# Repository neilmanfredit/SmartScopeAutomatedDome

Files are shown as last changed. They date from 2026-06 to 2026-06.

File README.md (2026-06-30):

# SmartScopeAutomatedDome

> **3D-printed automated observatory domes for the ZWO Seestar S50**  
> Three versions — choose the one that fits your setup and ambition.






---

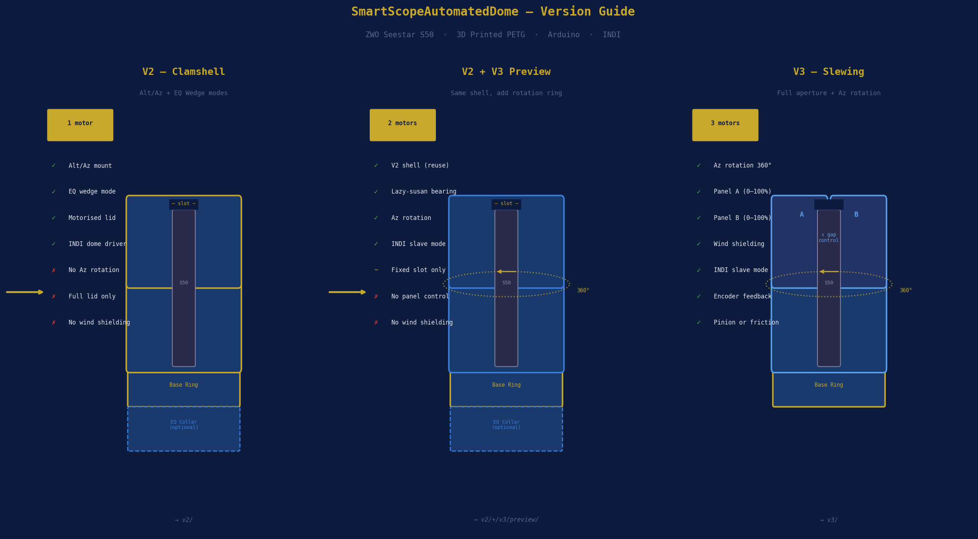
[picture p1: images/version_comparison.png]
Version Comparison


---

## Which version do I need?

Three versions exist, each adding capability on top of the last. You don't need to start at V2 — pick the one that matches what you actually want to do.

| | [V2 — Clamshell](#v2--clamshell) | [V3 — Slewing](#v3--slewing-dome) |
|---|---|---|
| **Best for** | Protecting scope overnight, simple open/close | Unattended imaging, wind shielding, precise aperture |
| **Modes** | Alt/Az + EQ wedge | Alt/Az + EQ wedge |
| **Motors** | 1 (opens lid) | 3 (Az rotation + Panel A + Panel B) |
| **Controller** | Arduino Nano | Arduino Mega 2560 |
| **Dome rotation** | Static | 360° motorised |
| **Aperture** | Full lid open or closed | Two independent panels, 0–100% each |
| **Wind shielding** | None | Yes — closed side always faces wind |
| **INDI slave mode** | No | Yes — dome tracks scope azimuth automatically |
| **Az encoder** | None | TCRT5000 IR, 36-slot, 0.0375°/step |
| **Drive options** | M8 lead screw | Ring gear + pinion OR friction wheel |
| **Est. build cost** | ~£89 | ~£140 |
| **Est. print time** | ~25 h | ~38 h |
| **Complexity** | Moderate | High |
| **README** | **[→ v2/README.md](v2/README.md)** | **[→ v3/README_V3_ADDENDUM.md](v3/README_V3_ADDENDUM.md)** |

---

## V2 — Clamshell

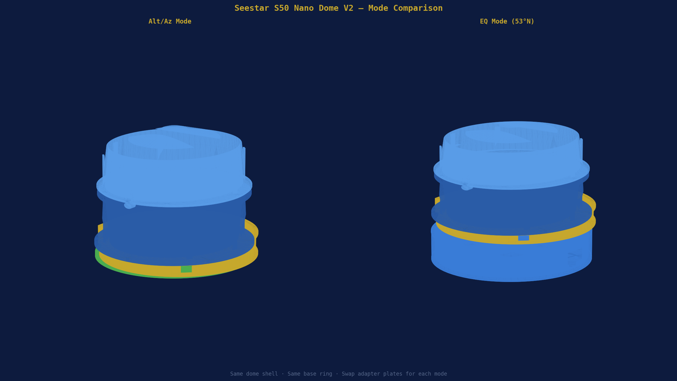
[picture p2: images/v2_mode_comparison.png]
V2 Mode Comparison


**The right choice if:** you want a dome that opens and closes to protect the scope, works in both Alt/Az and EQ modes, and you want something straightforward to build and commission.

V2 is a motorised clamshell — one NEMA 17 stepper drives an M8 lead screw that lifts the upper half of the dome. The dome sits still; only the lid moves. An Arduino Nano presents a serial command interface and the INDI driver handles open, close, park, and abort from within KStars/Ekos.

The key design decision in V2 is the **swappable adapter plate** — one base ring works for both modes:

- **Alt/Az** — adapter plate threads straight onto the S50 tripod
- **EQ** — a 110 mm extension collar raises the dome over your existing wedge

The dome interior (252 × 230 mm) gives the S50 complete freedom of movement. No scope-locating ribs — the scope floats inside the cavity in any position.

**[→ Full V2 README and build guide](v2/README.md)**

---

## V3 — Slewing Dome

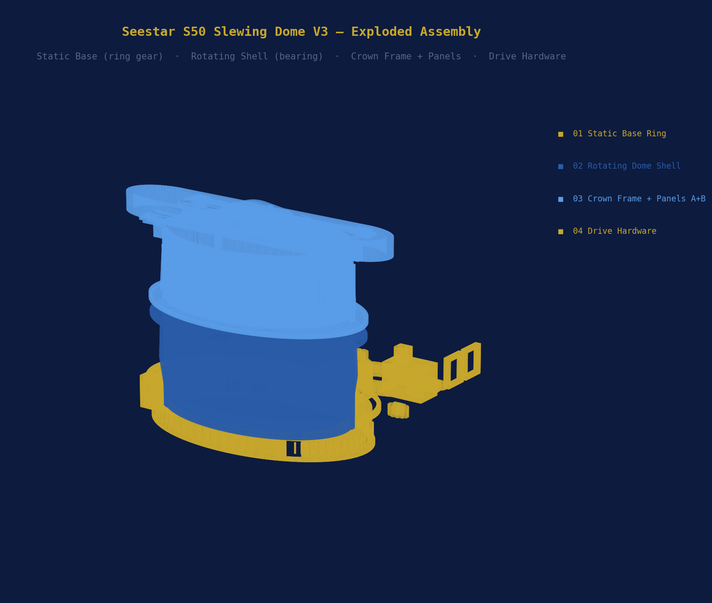
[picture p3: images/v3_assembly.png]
V3 Assembly


**The right choice if:** you want the dome to track the scope automatically, shield the scope from wind on the closed side, and control exactly how wide the aperture is.

V3 keeps the same dome shell dimensions as V2 but adds a **300 mm lazy-susan bearing** so the whole dome rotates in azimuth under Motor 1. The crown slot is replaced by two independently driven panels — Motor 2 moves Panel A, Motor 3 moves Panel B — each on its own M6 lead screw and LM8UU linear guide.

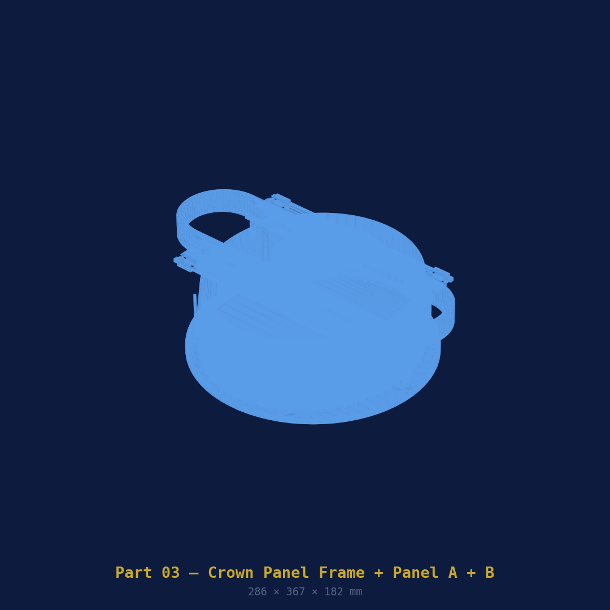
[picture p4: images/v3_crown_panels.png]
V3 Crown Panels


In INDI slave mode the driver reads the mount's RA/Dec, converts to azimuth, and slews the dome every 5 seconds (configurable) to keep the opening aligned with the telescope. A 2° dead-band prevents hunting on minor mount movements. The closed side of the dome permanently blocks wind and dew from the opposite direction.

Two Az drive mechanisms are included in the files — choose at assembly time:

- **Ring gear + pinion** — 72:12 = 6:1 reduction, 0.0375°/step, fully printed
- **Friction wheel** — rubber wheel presses on dome outer rim, simpler to set up

**V3 uses the same base ring bottom flange as V2**, so the Alt/Az and EQ adapter plates from V2 carry across directly. No reprinting the adapters.

**[→ Full V3 README and build guide](v3/README_V3_ADDENDUM.md)**

---

## Shared architecture

Both versions are built on the same mechanical and software foundations.

### Dome shell

All versions use the same outer dome geometry — 261 × 239 mm outer, 252 × 230 mm interior. The S50 (142.5 × 130 × 257 mm body) has 55 mm clearance each side, 50 mm front/rear, and 40 mm above. The clearances are designed around the worst-case EQ mode position at 53°N latitude (Stockport) — the scope tilted 53° on the polar axis, rotating through all RA positions. At no point does the scope contact the dome interior.

### INDI integration

Both drivers appear under the **Domes** group in KStars/Ekos. Both implement the INDI Dome interface — open, close, park, abort. V3 adds `DOME_CAN_ROTATE`, `DOME_CAN_SYNC`, and INDI slave mode. Standard Ekos observatory automation works with both.

### Firmware protocol

Both use plain-text serial at 9600 baud. Commands are human-readable (`OPEN`, `CLOSE`, `GOTO 180.0`, `STATUS`). You can test the dome from any terminal — no special tools needed.

### Materials and print settings

All parts: **PETG on Bambu Lab H2S**, 0.20 mm layer height, 30% Gyroid infill, 4 walls, tree supports. Settings are embedded in every `.3mf` file. The large dome shells and base ring require the H2S **320 × 320 mm extended build volume** — rotate the base ring 45° in Bambu Studio to fit.

---

## Repository structure

```
SmartScopeAutomatedDome/
│
├── README.md                    ← You are here
│
├── v2/                          ← Clamshell dome (Alt/Az + EQ)
│   ├── README.md                ← Full V2 build guide
│   ├── openscad/                ← 7 .scad source files
│   ├── 3mf/                     ← 6 Bambu Studio .3mf files
│   ├── firmware/                ← Arduino Nano firmware
│   ├── indi/                    ← INDI dome driver (clamshell)
│   └── images/                  ← 11 renders and diagrams
│
├── v3/                          ← Slewing dome (Az rotation + panels)
│   ├── README_V3_ADDENDUM.md    ← Full V3 build guide
│   ├── openscad/                ← 5 .scad source files
│   ├── 3mf/                     ← 4 Bambu Studio .3mf files
│   ├── firmware/                ← Arduino Mega 2560 firmware
│   ├── indi/                    ← INDI slewing dome driver
│   └── images/                  ← 6 renders and diagrams
│
└── images/                      ← Main README images
    ├── version_comparison.png
    ├── v2_mode_comparison.png
    ├── v2_altaz_assembly.png
    ├── v3_assembly.png
    └── v3_crown_panels.png
```

---

## Quick start

**V2:**
```bash
# Print: v2/3mf/01_base_ring.3mf through 05_hardware_parts.3mf
# Upload firmware
arduino-cli compile --fqbn arduino:avr:nano v2/firmware/dome_controller/dome_controller.ino
arduino-cli upload -p /dev/ttyUSB0 --fqbn arduino:avr:nano v2/firmware/dome_controller/dome_controller.ino
# Build and install INDI driver
cd v2/indi && mkdir build && cd build && cmake -DCMAKE_INSTALL_PREFIX=/usr .. && make -j4 && sudo make install
indiserver -v indi_seestar_nano_dome
```

**V3:**
```bash
# Print: v3/3mf/01_base_ring.3mf through 04_drive_hardware.3mf
# Upload firmware (Arduino Mega)
arduino-cli compile --fqbn arduino:avr:mega v3/firmware/dome_controller_v3/dome_controller_v3.ino
arduino-cli upload -p /dev/ttyUSB0 --fqbn arduino:avr:mega v3/firmware/dome_controller_v3/dome_controller_v3.ino
# Build and install INDI driver
cd v3/indi && mkdir build && cd build && cmake -DCMAKE_INSTALL_PREFIX=/usr .. && make -j4 && sudo make install
indiserver -v indi_seestar_slewing_dome
```

---

## Parts sourcing

All hardware links (AliExpress search URLs) are in each version's README under the Bill of Materials section.

Common to both versions: NEMA 17 stepper, A4988 driver, M8 stainless rod, F688ZZ bearing, Omron SS-5GL limit switches, M4/M5 fasteners, PETG filament.

V3 additions: 300 mm lazy-susan bearing, 8 mm guide rods, LM8UU linear bearings, M6 threaded rod, TCRT5000 IR sensor, Arduino Mega 2560, 30 mm rubber wheel.

---

## Scope compatibility

The dome interior dimensions are sized for the **ZWO Seestar S50** (142.5 × 130 × 257 mm). To adapt for a different scope, edit `openscad/params.scad` in either version — update `s50_w`, `s50_d`, `s50_h` and re-export. All clearances and bearing seats recalculate automatically.

Tested clearances work for the **S50 in equatorial mode at 53°N**. For other latitudes, update `LATITUDE` in `params.scad`.

---

## Contributing

Issues and pull requests welcome. Before starting significant structural changes please open an issue to align on approach.

If you build either version, photos of the completed dome are very welcome — open a Discussion.

---

## Licence

Copyright © Neil Manfred. Licensed under the Creative Commons Attribution-NonCommercial-NoDerivatives 4.0 International License. Commercial use and derivative works are not permitted. — see [LICENSE](LICENSE) — CC BY-NC-SA 4.0, non-commercial use only.

---

*Built by [@neilmanfredit](https://github.com/neilmanfredit)*

---

## Gallery

### M42 — Orion Nebula

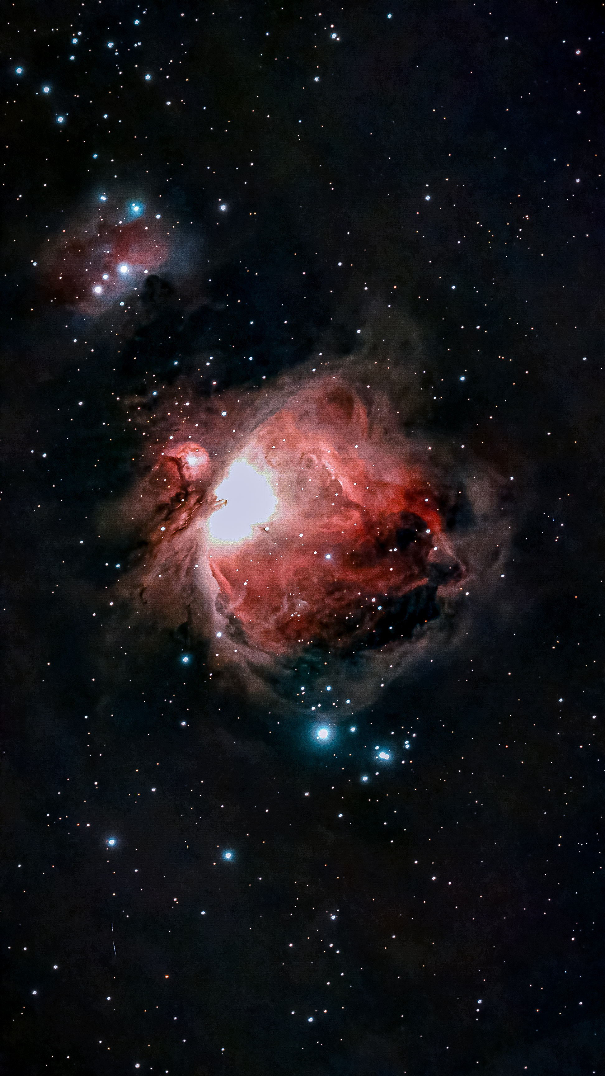
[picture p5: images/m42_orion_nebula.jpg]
Seestar S50 picture of M42


*Captured with the ZWO Seestar S50, 31 December 2025 — Bodmin Moor, Cornwall.*

The Orion Nebula (M42) captured from Bodmin Moor on New Year's Eve 2025. Bodmin Moor is one of the darkest sites in southern England, and the skies here show it — the image reveals the Trapezium cluster blazing at the core, four young massive stars responsible for ionising the surrounding gas and producing the characteristic red hydrogen-alpha glow. The Running Man Nebula (NGC 1977) is visible in the upper left, its blue reflection nebulosity contrasting with the warmer tones of M42. Dark dust lanes cut through the nebula, forming the distinctive fish-mouth shape around the bright central region. The Orion Nebula sits approximately 1,344 light years from Earth and is one of the most studied star-forming regions in the Milky Way. A stellar result from a 50mm aperture scope under genuinely dark skies.

---

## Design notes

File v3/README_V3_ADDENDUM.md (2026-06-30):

# V3 Addendum — Slewing Dome with Independent Aperture Panels

> This addendum extends the [main README](../README.md).  
> V3 adds full azimuth rotation and two independently controlled crown panels.

---

V3 Assembly

---

## What V3 Adds

| Feature | V2 Clamshell | V3 Slewing |
|---|---|---|
| Dome rotation | Static | Full 360° Az rotation |
| Aperture control | One motor opens full lid | Two independent panels (0–100%) |
| Wind shielding | None | Closed side always faces wind |
| Motors | 1 | 3 (Az + Panel A + Panel B) |
| Controller | Arduino Nano | Arduino Mega 2560 |
| Az feedback | None | TCRT5000 IR encoder, 36-slot disk |
| INDI slave mode | No | Yes — dome tracks scope Az automatically |
| Drive options | Lead screw | Ring gear + pinion OR friction wheel |

---

## How It Works

The dome shell sits on a **300 mm lazy-susan bearing** and rotates freely over the static base ring. A NEMA 17 motor (Motor 1) drives the dome in azimuth — either via a **printed ring gear + pinion** (72:12 = 6:1 ratio, 0.0375°/step resolution) or a **rubber friction wheel** pressing on the smooth outer rim. Both drive options are included in the files; choose at assembly time.

At the crown, two sliding panels (Panel A left, Panel B right) move independently on 8 mm guide rods driven by M6 × 1.0 mm lead screws (Motor 2 and Motor 3). Each panel can be positioned from fully closed to fully open (85 mm travel). This lets you dial in exactly how wide the aperture is and which side is shielded.

In INDI slave mode the driver reads the mount's RA/Dec every 5 seconds (configurable), converts to azimuth, and slews the dome to keep the open gap aligned with the scope. The 2° dead-band (configurable) prevents hunting on minor mount movements.

---

## System Architecture

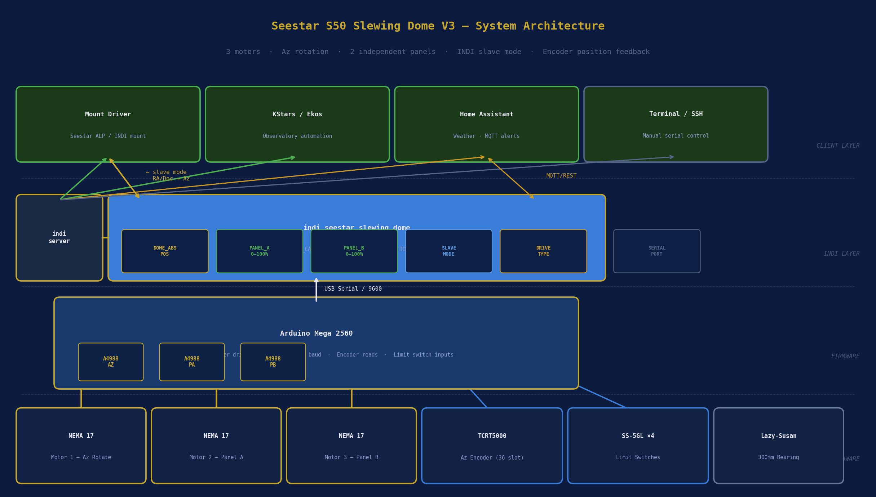
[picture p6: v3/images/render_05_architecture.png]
Architecture


| Layer | Component | Role |
|---|---|---|
| **Hardware** | 3× NEMA 17 + 3× A4988 + TCRT5000 + 4× SS-5GL | Motion + sensing |
| **Firmware** | Arduino Mega 2560 (`dome_controller_v3.ino`) | Serial command interface |
| **INDI** | `indi_seestar_slewing_dome` | Full slewing dome driver |
| **Client** | KStars/Ekos + Seestar ALP + HA | Control, slave mode, weather |

---

## Printed Parts

### Part 01 — Static Base Ring V3

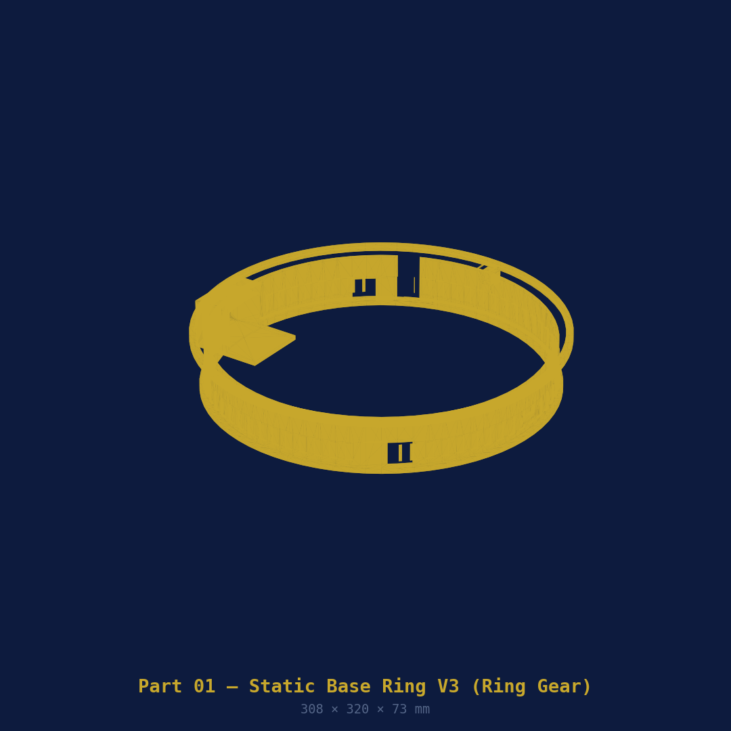
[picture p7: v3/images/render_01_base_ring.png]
Base Ring


Sits on the tripod or EQ extension (from V2 — fully compatible). Does not rotate.  
Contains the ring gear (72 teeth, module 2) on its outer rim for pinion drive, a smooth outer rail for friction drive, the Az motor pocket, the Az encoder IR sensor bracket, and an enlarged electronics bay (Arduino Mega 2560 + 3× A4988).

| Property | Value |
|---|---|
| File | `openscad/01_base_ring.scad` |
| 3MF | `3mf/01_base_ring.3mf` |
| Outer diameter | ~314 mm + gear teeth |
| Est. print time | ~7 h |
| Filament | ~260 g PETG |
| Orientation | Flat, open top face up |
| Supports | None |
| Bed | 320 × 320 mm — rotate 45° |

---

### Part 02 — Rotating Dome Shell V3

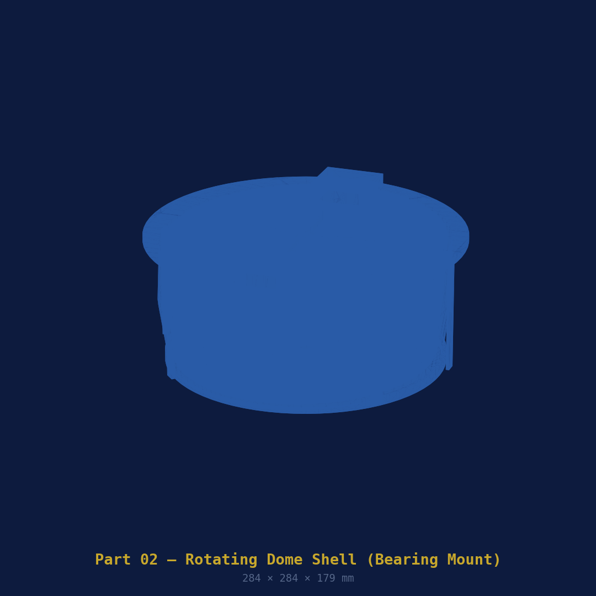
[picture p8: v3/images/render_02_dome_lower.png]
Dome Shell


This part **rotates** on the lazy-susan bearing. The bearing inner race (240 mm) bolts to the shell underside with 8× M4 bolts. The two panel motors (NEMA 17 #2 and #3) mount on the crown rim and rotate with the shell. The Az encoder disk attaches to the centre hub underneath.

| Property | Value |
|---|---|
| File | `openscad/02_dome_lower.scad` |
| 3MF | `3mf/02_dome_lower.3mf` |
| Interior | 252 × 230 mm — scope floats freely |
| Bearing seat | 240 mm ID (lazy-susan inner race) |
| Est. print time | ~11 h |
| Filament | ~330 g PETG |
| Orientation | Flat bottom on plate, interior up |
| Supports | Tree auto |
| Bed | 320 × 320 mm |

---

### Part 03 — Crown Panel Frame + Panel A + Panel B

Crown Panels

Three items in one file — export the frame and each panel separately for printing.

The **Crown Frame** bolts to the dome shell top flange and houses the full-length slot, the 8 mm guide rods, and the M6 lead screw bores. **Panel A** (left, Motor 2) and **Panel B** (right, Motor 3) each ride on two LM8UU linear bearings along the guide rods. Each panel has a captured M6 nut with anti-rotation tab. The panels overlap by 10 mm at centre when both are closed.

| Item | Print time | Filament |
|---|---|---|
| Crown Frame | ~8 h | ~250 g |
| Panel A | ~2 h | ~70 g |
| Panel B | ~2 h | ~70 g |

| Property | Value |
|---|---|
| File | `openscad/03_crown_panels.scad` |
| 3MF | `3mf/03_crown_panels.3mf` |
| Slot width (max open) | 80 mm |
| Panel travel | 85 mm each |
| Guide rods | 8 mm OD × 290 mm (order separately) |
| Linear bearings | LM8UU (order separately) |
| Orientation | Frame: split face down. Panels: flat. |
| Supports | Frame: tree auto. Panels: none. |

---

### Part 04 — Drive Hardware Parts V3

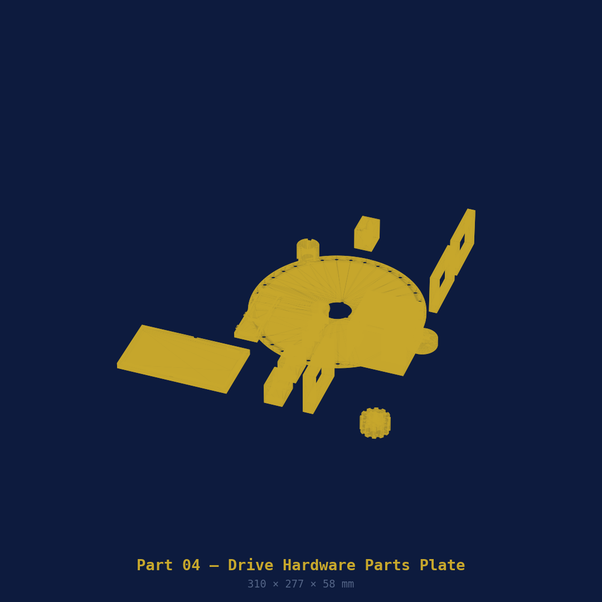
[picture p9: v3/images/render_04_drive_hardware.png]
Drive Hardware


All small parts on one plate. Export by module name for individual printing.

| Sub-part | Qty | Purpose |
|---|-----|---|
| Az pinion gear (04a) | 1 | Module 2, 12T — meshes with base ring (pinion drive) |
| Friction wheel mount (04b) | 1 | Holds NEMA 17 + rubber wheel on dome rim |
| Az motor bracket (04c) | 1 | Mounts Az NEMA 17 in base ring rear |
| Panel motor bracket (04d) | 2 | Mounts Panel A+B motors at crown |
| M6 bearing block (04e) | 2 | Lead screw lower end, F626ZZ bearing |
| M6 pivot arm (04f) | 2 | Connects M6 rod to panel |
| Az encoder disk (04g) | 1 | 36-slot, mounts on dome shell underside hub |
| IR sensor bracket (04h) | 1 | Mounts TCRT5000 on base ring, faces disk |
| Arduino Mega tray (04i) | 1 | Snap-fit, electronics bay |
| Triple A4988 tray (04j) | 1 | 3× drivers side by side, labelled AZ/PA/PB |
| Slip-ring spacer (04k) | 1 | Cable management through centre bore |

---

## Additional Hardware (V3 only)

> 💡 Prices are approximate AliExpress pricing at time of writing and will vary by seller. V3-specific hardware only — common items shared with V2 (M8 rod, F688ZZ bearing, M4/M5 fasteners, etc.) are in the [main V2 BOM](../v2/README.md#bill-of-materials) and not repeated here.

| Item | Qty | Approx. Cost | AliExpress |
|---|-----|---|---|
| 300 mm lazy-susan bearing | 1 | £9 | [🔗 Search](https://www.aliexpress.com/w/wholesale-300mm-lazy-susan-bearing-turntable.html) |
| 8 mm OD smooth rod, 300 mm (guide rods) | 2 | £6 | [🔗 Search](https://www.aliexpress.com/w/wholesale-8mm-smooth-rod-300mm-linear.html) |
| LM8UU linear bearing | 4 | £4 | [🔗 Search](https://www.aliexpress.com/w/wholesale-lm8uu-linear-bearing.html) |
| M6 × 1.0 threaded rod, 150 mm (×2) | 2 | £4 | [🔗 Search](https://www.aliexpress.com/w/wholesale-m6-threaded-rod-150mm-stainless.html) |
| F626ZZ flanged bearing (6×19×6) | 2 | £3 | [🔗 Search](https://www.aliexpress.com/w/wholesale-f626zz-flanged-bearing.html) |
| M6 flexible shaft coupler 5 mm→6 mm | 2 | £4 | [🔗 Search](https://www.aliexpress.com/w/wholesale-flexible-shaft-coupler-5mm-6mm.html) |
| NEMA 17 stepper motor (×3 total) | 3 | £30 | [🔗 Search](https://www.aliexpress.com/w/wholesale-nema-17-stepper-motor-40mm.html) |
| A4988 stepper driver with heatsink (×3) | 3 | £9 | [🔗 Search](https://www.aliexpress.com/w/wholesale-a4988-stepper-driver-heatsink.html) |
| Arduino Mega 2560 | 1 | £12 | [🔗 Search](https://www.aliexpress.com/w/wholesale-arduino-mega-2560-ch340.html) |
| TCRT5000 IR reflective sensor | 1 | £2 | [🔗 Search](https://www.aliexpress.com/w/wholesale-tcrt5000-ir-reflective-sensor.html) |
| Omron SS-5GL micro-switch (×4 total) | 4 | £6 | [🔗 Search](https://www.aliexpress.com/w/wholesale-omron-ss-5gl-micro-switch.html) |
| 30 mm rubber wheel (friction drive) | 1 | £3 | [🔗 Search](https://www.aliexpress.com/w/wholesale-30mm-rubber-wheel-shaft.html) |
| 6-wire slip ring, 12 mm OD | 1 | £6 | [🔗 Search](https://www.aliexpress.com/w/wholesale-6-wire-slip-ring-12mm.html) |
| **V3-specific subtotal** | | **£98** | |

> **Slip ring note:** The 6-wire slip ring routes the panel motor wires (6 wires: coil A+B for Motor 2, coil A+B for Motor 3, plus 2 limit switch wires) through the dome centre bore as it rotates. You can omit it if you have sufficient cable slack for 360° rotation without a slip ring — 500 mm of extra cable on each wire is usually enough for a dome that only ever sweeps ±180°. Omitting it saves £6.

### Total Build Cost (V3 complete)

V3 reuses the M8 lead screw, F688ZZ bearing, fasteners, foam seal, and tripod/EQ adapter hardware from V2 — those costs carry over alongside the V3-specific items above.

| | Without filament | With filament |
|---|---|---|
| V2 shared hardware (excl. filament) | £53 | £53 |
| V3-specific hardware (above) | £98 | £98 |
| PETG filament (~5 spools total, V2 dome shells + V3 parts) | — | £70 |
| **Total** | **£151** | **£221** |

> Filament estimate covers all V3 plates (base ring ~260g, dome shell ~330g, crown frame + panels ~390g, drive hardware ~110g — roughly 1.1kg / 1.5 spools) plus the shared V2 dome shells if not already printed (~3 spools). If you've already built V2 and are upgrading to V3, you only need the extra ~1.5 spools for the new V3-specific parts, bringing the incremental cost to roughly **£98–£130** depending on spool pricing.

---

## Firmware

Source: [`firmware/dome_controller_v3/dome_controller_v3.ino`](firmware/dome_controller_v3/dome_controller_v3.ino)

**Target:** Arduino Mega 2560 (not Nano — needs 11 digital outputs for 3× motor drivers)

### Serial Command Reference

| Command | Response | Description |
|---|---|---|
| `GOTO ddd.d` | `SLEWING:ddd.d` → `AZ_DONE:ddd.d` | Slew to azimuth |
| `SYNC ddd.d` | `SYNCED:ddd.d` | Set current position |
| `STATUS` | `AZ:ddd.d PA:nn PB:nn MOVING:n` | Full status |
| `STOP` / `ABORT` | `STOPPED` | Halt all motors |
| `PA OPEN` | `PA_DONE:136000` | Panel A fully open |
| `PA CLOSE` | `PA_DONE:0` | Panel A fully closed |
| `PA POS nn` | `PA_DONE:nnnnnn` | Panel A to nn% |
| `PB OPEN` | `PB_DONE:136000` | Panel B fully open |
| `PB CLOSE` | `PB_DONE:0` | Panel B fully closed |
| `PB POS nn` | `PB_DONE:nnnnnn` | Panel B to nn% |
| `PANELS OPEN` | `PANELS_OPEN` | Both panels fully open |
| `PANELS CLOSE` | `PANELS_CLOSED` | Both panels closed |
| `PARK` | `PARKED` | Close panels, slew to Az 0° |
| `HOME` | `HOMED` / `HOME_FAILED` | Home encoder on slot transition |

### Upload

```bash
arduino-cli core install arduino:avr
arduino-cli compile --fqbn arduino:avr:mega \
  firmware/dome_controller_v3/dome_controller_v3.ino
arduino-cli upload -p /dev/ttyUSB0 --fqbn arduino:avr:mega \
  firmware/dome_controller_v3/dome_controller_v3.ino
```

---

## INDI Driver

Source: [`indi/seestar_slewing_dome.cpp`](indi/seestar_slewing_dome.cpp)

Appears in KStars/Ekos as **"Seestar Slewing Dome"**.

### Build

```bash
sudo apt install libindi-dev libnova-dev cmake build-essential
cd indi && mkdir build && cd build
cmake -DCMAKE_INSTALL_PREFIX=/usr ..
make -j4 && sudo make install
indiserver -v indi_seestar_slewing_dome
```

### INDI Properties

| Property | Tab | Type | Description |
|---|-----|---|---|
| `DOME_ABSOLUTE_POSITION` | Main | Number | Current / target Az (0–359.9°) |
| `PANEL_A` | Main | Number | Panel A position (0–100%) |
| `PANEL_B` | Main | Number | Panel B position (0–100%) |
| `DOME_SHUTTER` | Main | Switch | Open = PANELS OPEN, Close = PANELS CLOSE |
| `SLAVE_MODE` | Options | Switch | Slave on/off |
| `SLAVE_SETTINGS` | Options | Number | Update interval (s) + dead-band (°) |
| `DRIVE_TYPE` | Options | Switch | Pinion or friction drive |
| `SERIAL_PORT` | Options | Text | Serial port (default /dev/ttyUSB0) |

### Slave Mode Setup in Ekos

1. Load mount driver (Seestar ALP or StellarMate Seestar)
2. Load `indi_seestar_slewing_dome`
3. In Ekos → Observatory → Dome → set **Active telescope** to your mount
4. On driver Options tab → Slave Mode → **Active**
5. Set Update interval (default 5 s) and Dead-band (default 2°)
6. Dome will now track scope azimuth automatically

---

## Assembly Notes (V3 specific)

### Rotation Drive — Pinion Option

1. Press Az pinion (04a) onto NEMA 17 shaft, D-flat aligned — set screw M3
2. Mount Az motor bracket (04c) in base ring rear pocket
3. Position motor so pinion teeth mesh cleanly with ring gear — 0.1–0.2 mm backlash
4. Secure bracket; verify dome rotates smoothly under hand pressure

### Rotation Drive — Friction Wheel Option

1. Press 30 mm rubber wheel onto NEMA 17 shaft
2. Mount friction wheel bracket (04b) — adjust radial slot for firm contact with dome rim
3. Tighten when wheel compresses ~1 mm into dome outer surface

### Lazy-Susan Bearing

1. Place bearing outer race into base ring top face recess (300 mm bore)
2. Lower rotating dome shell onto bearing — inner race rests in shell underside seat
3. 8× M4 × 12 bolts through shell underside flange into inner race — snug evenly
4. Dome should rotate with light hand force and no lateral wobble

### Crown Panel Guide Rods

1. Insert 8 mm guide rods through frame front bore → panel LM8UU bearings → rear bore
2. Rods should be a light press fit in the frame bores — epoxy if loose
3. Insert M6 lead screw through bearing block, through panel nut trap, couple to motor

### Az Encoder

1. Snap encoder disk (04g) onto dome shell underside hub — M3 × 6 screws × 3
2. Mount IR sensor bracket (04h) on base ring rim, align sensor to disk face
3. Gap: 2–5 mm between sensor and disk
4. Test: rotate dome by hand — `analogRead(A0)` should alternate HIGH/LOW 36× per revolution

### Commissioning Checklist

- [ ] Dome rotates freely on bearing — hand-push, no binding
- [ ] `HOME` command completes — encoder transitions detected
- [ ] `GOTO 90` slews to 90° ± 1° (verify with compass or protractor)
- [ ] `PA POS 50` moves Panel A to approximately half open
- [ ] `PB POS 50` moves Panel B independently
- [ ] `PANELS CLOSE` both panels seat flush, 10 mm centre overlap
- [ ] Slave mode: slew mount 10°, dome follows within 5 s
- [ ] `PARK` closes panels and slews to Az 0°
- [ ] Foam seals on panel edges compress evenly

---

*Part of the [SmartScopeAutomatedDome](https://github.com/neilmanfredit/SmartScopeAutomatedDome) project.*  
*Built by [@neilmanfredit](https://github.com/neilmanfredit)*

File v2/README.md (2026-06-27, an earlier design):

# SmartScopeAutomatedDome

> **Motorised 3D-printed clamshell observatory for the ZWO Seestar S50**  
> Supports **Alt/Az and EQ Wedge** modes · NEMA 17 stepper · Arduino Nano · INDI Dome driver · PETG on Bambu Lab H2S







---

Mode Comparison

---

## Overview

A portable, automated observatory dome sized to surround the **ZWO Seestar S50** (142.5 × 130 × 257 mm body) in both Alt/Az and equatorial (EQ wedge) configurations. The dome opens and closes like a clamshell via an M8 lead screw driven by a NEMA 17 stepper. An Arduino Nano handles the motor and limit switches and presents a standard serial interface consumed by a custom **INDI Dome driver** — integrating directly with KStars/Ekos for fully unattended imaging sessions.

Design reference: [Nano Dome V2](https://www.cloudynights.com/forums/topic/1000995-miniature-3d-printed-clamshell-observatory-nano-dome/) by spbalaji (Cloudy Nights, May 2026), substantially redesigned for the larger S50 body, full range of motion in both modes, and complete motorised automation.

### What changed from V1

| V1 | V2 |
|----|----|
| Single fixed mount mode | Alt/Az and EQ wedge — swappable adapter plates |
| 192 × 170 mm interior | 252 × 230 mm interior — scope moves completely freely |
| Scope locating ribs (gripped scope) | No ribs — scope floats inside dome |
| 70 × 70 mm square crown aperture | Full-length front-to-back crown slot (80 mm wide) |
| M8 hinge pin | M10 hinge pin — stronger for larger, heavier lid |
| No wedge clearance | EQ extension collar adds 110 mm over wedge stack |
| 232 mm base ring diameter | 314 mm base ring — proportionate to larger dome |

---

## Table of Contents

- [How It Works](#how-it-works)
- [Modes](#modes)
- [System Architecture](#system-architecture)
- [Printed Parts](#printed-parts)
  - [Part 01 — Universal Base Ring](#part-01--universal-base-ring)
  - [Part 02a — Alt/Az Adapter Plate](#part-02a--altaz-adapter-plate)
  - [Part 02b — EQ Extension Collar + Adapter](#part-02b--eq-extension-collar--adapter)
  - [Part 03 — Dome Lower Half](#part-03--dome-lower-half)
  - [Part 04 — Dome Upper Half](#part-04--dome-upper-half)
  - [Part 05 — Hardware Parts Plate](#part-05--hardware-parts-plate)
- [Print Settings](#print-settings)
- [Bill of Materials](#bill-of-materials)
- [Wiring](#wiring)
- [Firmware](#firmware)
- [INDI Driver](#indi-driver)
- [Assembly](#assembly)
  - [Alt/Az Assembly](#altaz-assembly)
  - [EQ Assembly](#eq-assembly)
- [Commissioning](#commissioning)
- [Integration with Seestar ALP](#integration-with-seestar-alp)
- [Contributing](#contributing)
- [Licence](#licence)

---

## How It Works

The dome shell (lower + upper halves) sits around the S50 without touching it. The scope moves freely inside the cavity in any direction — the dome is purely a weather enclosure, not a structural mount. The full-length crown slot allows the scope to point from approximately 15° altitude up to zenith in both Alt/Az and EQ mode without clipping the dome interior.

The dome is opened and closed by a NEMA 17 stepper motor driving an M8 lead screw. The lead screw pushes and pulls the upper lid via a rear pivot arm. Two Omron SS-5 micro-switches provide hard stops at fully open and fully closed — the firmware checks both on every step, so there is no risk of overrun.

---

## Modes

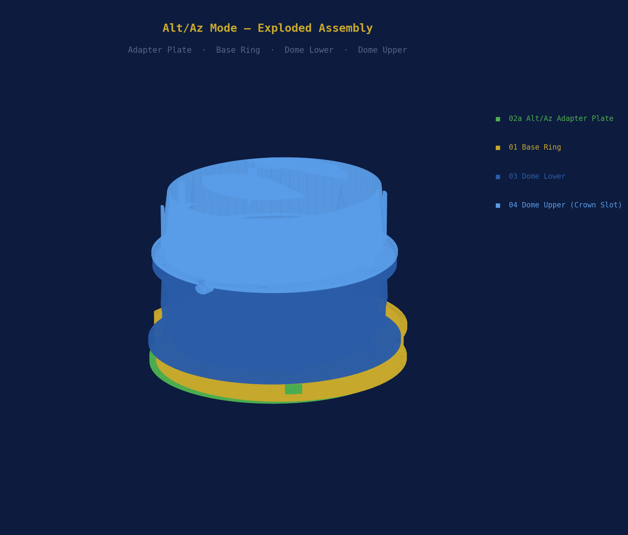
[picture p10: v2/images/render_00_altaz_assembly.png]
Alt/Az Assembly


**Alt/Az mode** — the dome mounts directly onto the S50's own tripod via the **Alt/Az Adapter Plate (02a)**. The adapter bolts to the base ring bottom flange and threads onto the tripod head via a 3/8" brass insert. Total stack height is the base ring + dome shell only.

---

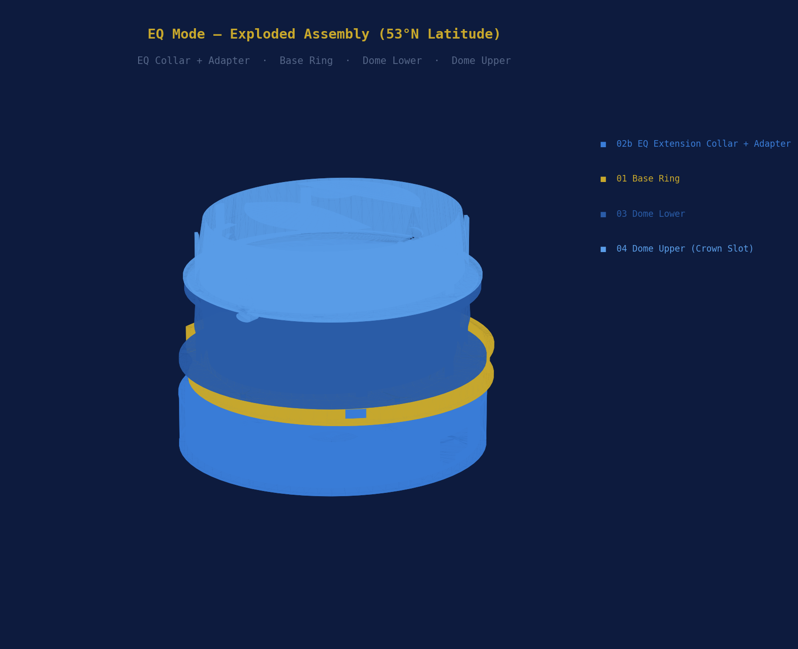
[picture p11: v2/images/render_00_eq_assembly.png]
EQ Assembly


**EQ mode (53°N latitude)** — the **EQ Extension Collar + Adapter (02b)** replaces the Alt/Az adapter. The adapter bolts to your existing 3D-printed wedge top plate (4× M4, 60 mm square bolt pattern). The 110 mm collar raises the base ring and dome shell above the wedge stack, providing full clearance for the scope tilted at 53° on the polar axis as it rotates through all RA positions.

**Switching modes:** Remove 6× M5 bolts from the base ring bottom flange, swap the adapter plate (or add/remove the extension collar), refit bolts. Takes about 10 minutes.

---

## System Architecture

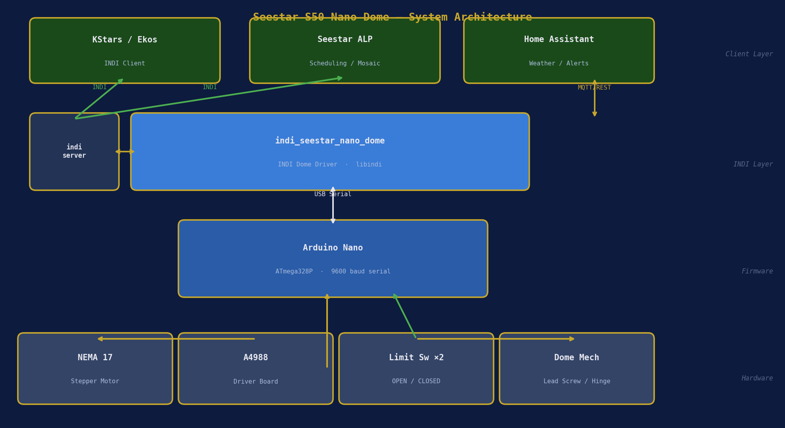
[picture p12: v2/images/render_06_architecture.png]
System Architecture


| Layer | Component | Role |
|---|---|---|
| **Hardware** | NEMA 17 + A4988 + limit switches | Physical motion |
| **Firmware** | Arduino Nano (`dome_controller.ino`) | Serial command interface |
| **INDI** | `indi_seestar_nano_dome` | Dome device driver |
| **Client** | KStars/Ekos · Seestar ALP · Home Assistant | Scheduling, weather, control |

---

## Printed Parts

All parts print in **PETG** on a Bambu Lab H2S. `.3mf` files with the full Bambu print profile embedded are in [`3mf/`](3mf/). The dome shell and base ring are too large for the H2S 256 × 256 mm standard bed — they require the **H2S extended build volume (320 × 320 mm)**. See notes per part.

You only print **one set of dome shells** regardless of mode. The only parts that differ between modes are the adapter plates.

---

### Part 01 — Universal Base Ring

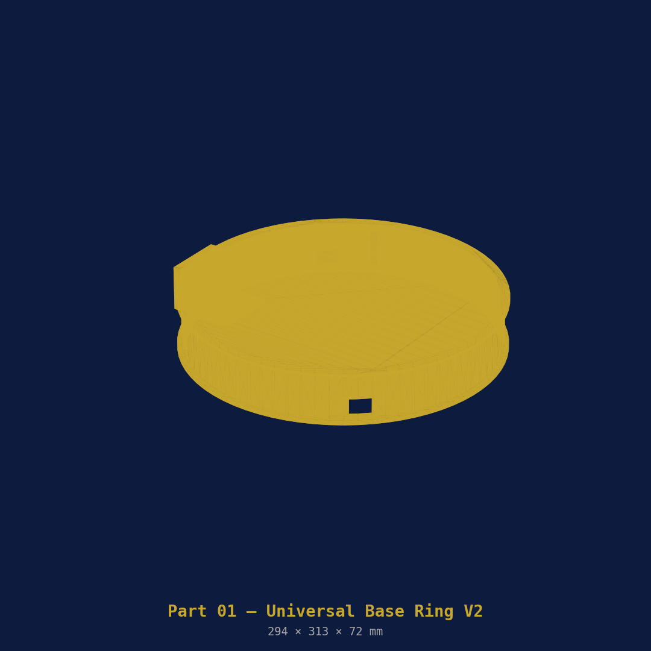
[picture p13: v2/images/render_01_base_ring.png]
Base Ring


The structural foundation common to both modes. Contains the motor housing, electronics bay, and lead screw mechanism. The bottom face accepts either adapter plate via 6× M5 bolts. The top flange mates with the dome lower half.

| Property | Value |
|---|---|
| File | `openscad/01_base_ring.scad` |
| 3MF | `3mf/01_base_ring.3mf` |
| Outer diameter | ~314 mm |
| Height | 65 mm |
| Est. print time | ~6 h |
| Filament | ~220 g PETG |
| Orientation | Flat, open top face up |
| Supports | None |
| Bed required | 320 × 320 mm (H2S extended) — rotate 45° on plate |

**Captured hardware:** NEMA 17 motor (rear pocket) · Arduino Nano tray · A4988 driver · M8 lead screw · electronics wiring bay

---

### Part 02a — Alt/Az Adapter Plate

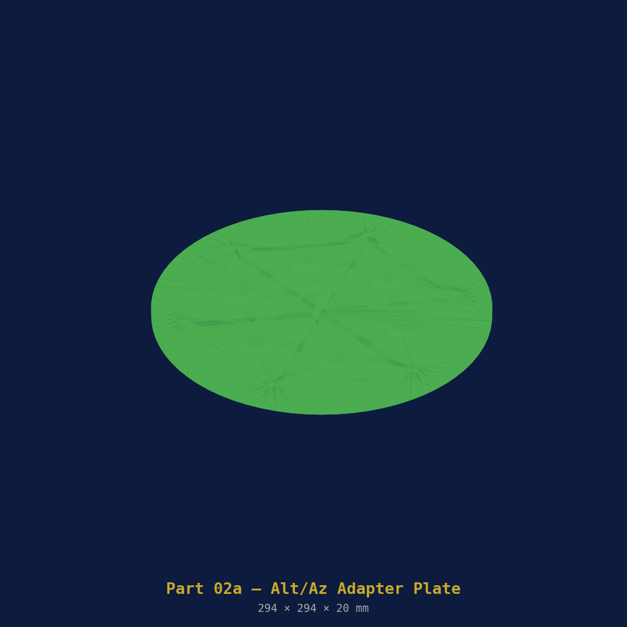
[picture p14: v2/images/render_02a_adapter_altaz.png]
Alt/Az Adapter


Sits between the base ring and the S50 tripod head. Labelled **ALT/AZ** on the top face. Threaded brass insert at centre accepts the S50 tripod's 3/8" thread via an M10 adaptor.

| Property | Value |
|---|---|
| File | `openscad/02a_adapter_altaz.scad` |
| 3MF | `3mf/02a_adapter_altaz.3mf` |
| Diameter | ~322 mm |
| Thickness | 12 mm |
| Est. print time | ~1.5 h |
| Filament | ~60 g PETG |
| Orientation | Flat, top face up |
| Supports | None |

**Hardware:** M10 × 12 mm brass knurled insert (centre) · 6× M5 cap head bolts (to base ring)

---

### Part 02b — EQ Extension Collar + Adapter

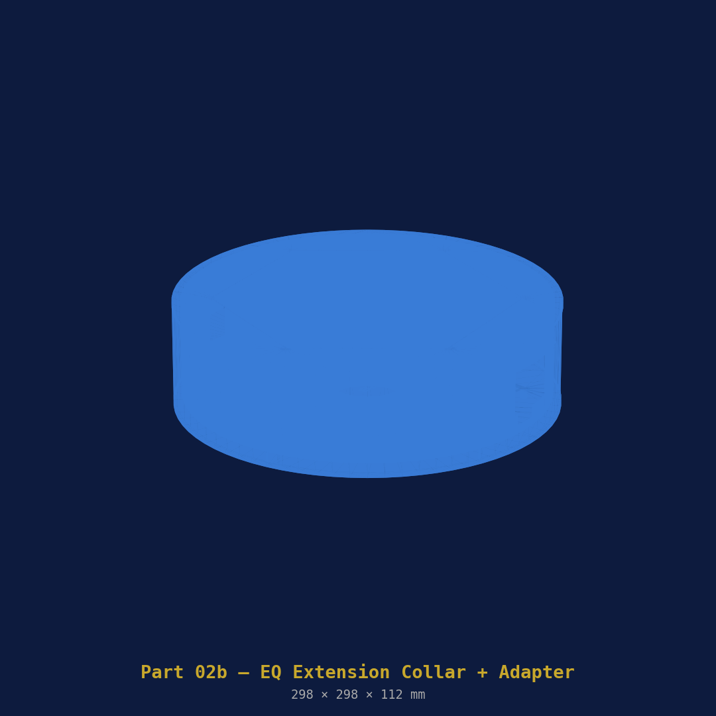
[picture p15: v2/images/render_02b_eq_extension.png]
EQ Extension


Two-part solution for EQ mode. The **adapter plate** (bottom) bolts to your existing wedge top plate. The **extension collar** (110 mm tall) raises the entire dome above the wedge stack, providing clearance for the scope rotating on the RA axis. Labelled **EQ** and **EQ MODE** respectively.

| Property | Value |
|---|---|
| File | `openscad/02b_eq_extension.scad` |
| 3MF | `3mf/02b_eq_extension.3mf` |
| Collar height | 110 mm |
| Wedge bolt pattern | 4× M4, 60 mm square (standard DIY S50 wedge) |
| Est. print time | Collar ~4 h · Adapter ~1 h |
| Filament | ~180 g + 55 g PETG |
| Orientation | Collar upright · Adapter flat |
| Supports | None |

> **Note:** The 60 mm square M4 bolt pattern matches the most common 3D-printed EQ wedge designs for the Seestar S50. If your wedge uses a different pattern, edit `openscad/02b_eq_extension.scad` — the bolt positions are clearly commented.

---

### Part 03 — Dome Lower Half

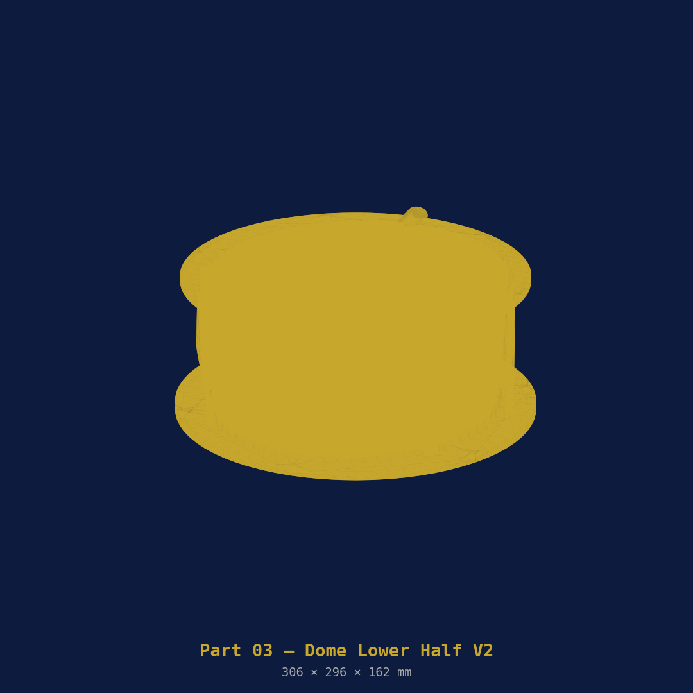
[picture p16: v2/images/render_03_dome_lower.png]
Dome Lower


The fixed lower shell. Ovoid cross-section to clear the S50 at all telescope positions in both modes. No scope-locating ribs — the scope floats freely. Bolts to the base ring top flange with 6× M4.

| Property | Value |
|---|---|
| File | `openscad/03_dome_lower.scad` |
| 3MF | `3mf/03_dome_lower.3mf` |
| Interior width | ~252 mm |
| Interior depth | ~230 mm |
| Split height | 145 mm |
| Est. print time | ~11 h |
| Filament | ~320 g PETG |
| Orientation | Flat bottom on plate, interior up |
| Supports | Tree auto (internal arch overhangs) |
| Bed required | 320 × 320 mm (H2S extended) |

**Features:** M10 hinge bosses left and right · Rear M8 lead screw nut trap · Front USB-C cable channel · Side motor cable chase

---

### Part 04 — Dome Upper Half

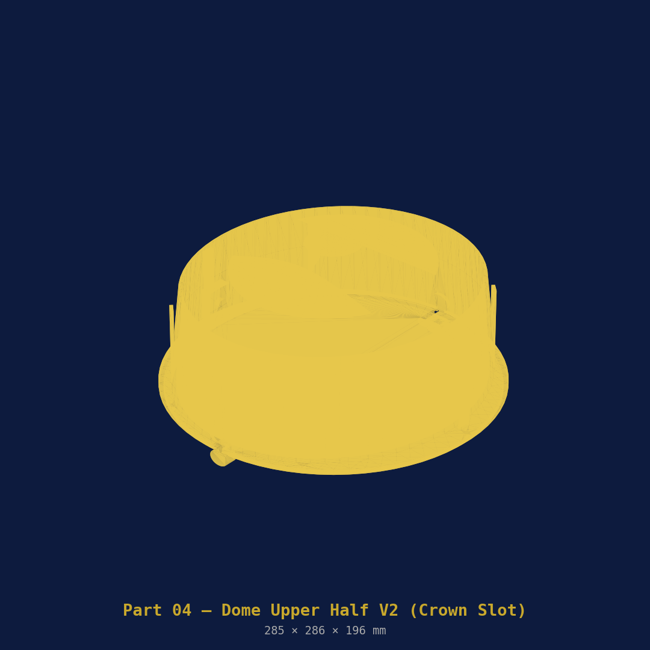
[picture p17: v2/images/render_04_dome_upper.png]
Dome Upper


The hinged lid. The key change from V1 is the **full-length crown slot** — an 80 mm wide opening running the full front-to-back depth of the dome. This allows the S50 to point from approximately 15° altitude to zenith in any azimuth in Alt/Az mode, and through the full RA rotation in EQ mode, without clipping the dome interior at any position.

| Property | Value |
|---|---|
| File | `openscad/04_dome_upper.scad` |
| 3MF | `3mf/04_dome_upper.3mf` |
| Crown slot | 80 mm wide × full dome depth |
| Hinge travel | ~110° |
| Est. print time | ~10 h |
| Filament | ~280 g PETG |
| Orientation | Split face **down** on plate (dome exterior up — best surface finish) |
| Supports | Tree auto |
| Bed required | 320 × 320 mm (H2S extended) |

**Features:** M10 hinge knuckles (female) · Lead screw pivot bracket (rear) · 8 mm sealing lip overlap · 3.5 mm foam seal channel at split face · Radiused slot edges (no cable snag)

---

### Part 05 — Hardware Parts Plate

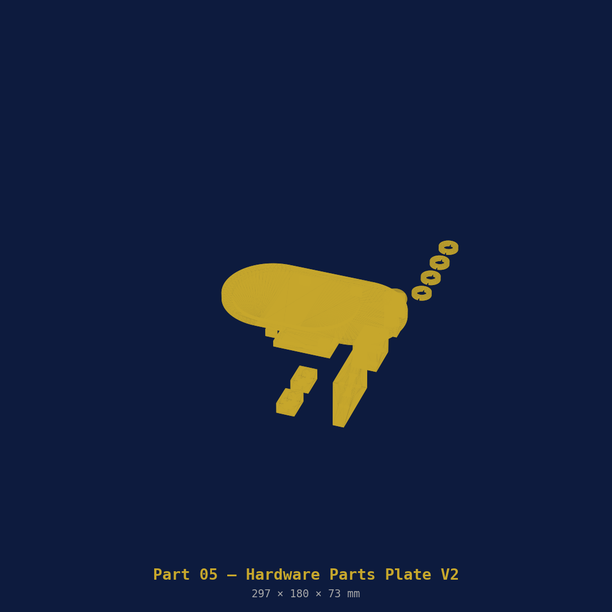
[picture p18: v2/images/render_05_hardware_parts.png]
Hardware Parts


All small hardware in a single plate print. Includes the optional **slot rain cover** (part 5g) which snaps over the crown slot when the dome is parked to prevent rain and dew ingress through the open slot.

| Property | Value |
|---|---|
| File | `openscad/05_hardware_parts.scad` |
| 3MF | `3mf/05_hardware_parts.3mf` |
| Est. print time | ~3.5 h |
| Filament | ~90 g PETG |
| Orientation | All flat, no supports |

| Sub-part | Qty | Purpose |
|---|-----|---|
| Motor mount bracket (5a) | 1 | Bolts NEMA 17 to base ring rear |
| Lead screw bearing block (5b) | 1 | Lower M8 rod end, F688 bearing |
| Lead screw pivot arm (5c) | 1 | Clevis connecting rod to lid |
| M10 hinge pin retainer clip (5d) | 4 | Snap clips, prevent pin walking |
| Limit switch bracket (5e) | 2 | Mounts Omron SS-5 (open + closed) |
| Arduino Nano tray (5f) | 1 | Snap-fit tray, electronics bay |
| Crown slot rain cover (5g) | 1 | Snaps over slot when dome parked |

---

## Print Settings

Embedded in every `.3mf` file. Open in Bambu Studio — settings load automatically.

| Setting | Value |
|---|---|
| Layer height | 0.20 mm |
| Walls | 4 |
| Top / bottom layers | 5 |
| Infill | 30% Gyroid |
| Supports | Tree (auto) |
| Brim | 5 mm outer only |
| Nozzle | 240 °C |
| Bed | 70 °C |
| Part cooling | 30% max |
| Max volumetric speed | 12 mm³/s |
| Machine | BambuLab H2S |

> **Print order:** Start with `05_hardware_parts.3mf` to validate PETG settings. Then the two adapter plates. Leave the large dome shells until you are confident in settings.

> **Bed size note:** The base ring (314 mm dia) and dome halves (~261 mm wide) require the H2S **320 × 320 mm extended build volume**. In Bambu Studio, rotate the base ring 45° on the plate so the diagonal fits within the bed.

---

## Bill of Materials

> 💡 **AliExpress links** are provided for every non-printed part below. Links go to search results rather than individual listings — search results stay current as listings come and go. Prices are approximate at time of writing; AliExpress pricing changes frequently.

### Electronics

| Item | Qty | Spec | AliExpress |
|---|-----|---|---|
| NEMA 17 stepper motor | 1 | 40 mm body, 1.5 A, 4-lead (17HS4401) | [🔗 Search](https://www.aliexpress.com/w/wholesale-nema-17-stepper-motor-40mm.html) |
| A4988 stepper driver | 1 | With aluminium heatsink | [🔗 Search](https://www.aliexpress.com/w/wholesale-a4988-stepper-driver-heatsink.html) |
| Arduino Nano | 1 | ATmega328P, CH340, USB-C | [🔗 Search](https://www.aliexpress.com/w/wholesale-arduino-nano-ch340-usb-c-atmega328p.html) |
| DuPont jumper wires | 20 | 20 cm, mixed M-F and M-M | [🔗 Search](https://www.aliexpress.com/w/wholesale-dupont-jumper-wires-20cm.html) |
| USB-A to USB-C cable | 1 | 1 m, for Arduino serial | [🔗 Search](https://www.aliexpress.com/w/wholesale-usb-a-to-usb-c-cable-1m.html) |
| 12 V 2 A DC power supply | 1 | 5.5/2.1 mm barrel jack, regulated | [🔗 Search](https://www.aliexpress.com/w/wholesale-12v-2a-dc-power-supply-adapter.html) |
| DC barrel jack socket | 2 | 5.5/2.1 mm panel mount | [🔗 Search](https://www.aliexpress.com/w/wholesale-dc-barrel-jack-5.5-2.1mm-panel.html) |

### Motion & Mechanical

| Item | Qty | Spec | AliExpress |
|---|-----|---|---|
| M8 × 1.25 threaded rod | 1 | 200 mm, 304 stainless — lead screw | [🔗 Search](https://www.aliexpress.com/w/wholesale-m8-threaded-rod-200mm-stainless.html) |
| M10 smooth rod | 1 | 100 mm, stainless — hinge pin | [🔗 Search](https://www.aliexpress.com/w/wholesale-m10-stainless-steel-rod-100mm.html) |
| M8 flange nut | 2 | Stainless, 1.25 mm pitch | [🔗 Search](https://www.aliexpress.com/w/wholesale-m8-flange-nut-stainless.html) |
| F688ZZ flanged bearing | 1 | 8 × 16 × 5 mm, shielded | [🔗 Search](https://www.aliexpress.com/w/wholesale-f688zz-flanged-bearing-8x16x5.html) |
| Flexible shaft coupler | 1 | 5 mm → 8 mm, aluminium jaw type | [🔗 Search](https://www.aliexpress.com/w/wholesale-flexible-shaft-coupler-5mm-8mm.html) |
| Omron SS-5GL micro-switch | 2 | 5 A 125 V, lever, NO/NC — limit switches | [🔗 Search](https://www.aliexpress.com/w/wholesale-omron-ss-5gl-micro-switch.html) |

### Fasteners & Inserts

| Item | Qty | Spec | AliExpress |
|---|-----|---|---|
| M10 brass knurled insert | 1 | 10 × 12 mm heat-set — Alt/Az tripod thread | [🔗 Search](https://www.aliexpress.com/w/wholesale-m10-brass-knurled-insert-nut.html) |
| M5 × 16 cap head bolt | 6 | Stainless — base ring to adapter | [🔗 Search](https://www.aliexpress.com/w/wholesale-m5-x-16mm-socket-cap-bolt-stainless.html) |
| M4 × 16 cap head bolt | 12 | Stainless — dome flanges | [🔗 Search](https://www.aliexpress.com/w/wholesale-m4-x-16mm-cap-head-bolt-stainless.html) |
| M4 × 12 cap head bolt | 4 | Stainless — EQ adapter to wedge | [🔗 Search](https://www.aliexpress.com/w/wholesale-m4-x-12mm-cap-head-bolt-stainless.html) |
| M4 × 8 cap head bolt | 8 | Stainless — motor bracket | [🔗 Search](https://www.aliexpress.com/w/wholesale-m4-x-8mm-cap-head-bolt-stainless.html) |
| M3 × 8 cap head bolt | 4 | Stainless — motor face bolts | [🔗 Search](https://www.aliexpress.com/w/wholesale-m3-x-8mm-socket-cap-bolt-stainless.html) |
| M4 hex nut | 20 | Stainless | [🔗 Search](https://www.aliexpress.com/w/wholesale-m4-hex-nut-stainless-steel.html) |
| M5 hex nut | 6 | Stainless | [🔗 Search](https://www.aliexpress.com/w/wholesale-m5-hex-nut-stainless-steel.html) |
| Brass insert nut assortment | 1 set | M3/M4/M5 heat-set, for PETG | [🔗 Search](https://www.aliexpress.com/w/wholesale-brass-heat-set-insert-nut-m3-m4-m5.html) |

### Consumables & Alt/Az Specific

| Item | Qty | Spec | AliExpress |
|---|-----|---|---|
| 3/8" to M10 tripod thread adaptor | 1 | Alt/Az mode only | [🔗 Search](https://www.aliexpress.com/w/wholesale-3-8-inch-to-m10-tripod-adapter.html) |
| 3 mm foam weatherstrip | 1 | 700 mm length, self-adhesive | [🔗 Search](https://www.aliexpress.com/w/wholesale-3mm-foam-weatherstrip-self-adhesive.html) |
| Epoxy adhesive | 1 | 2-part, e.g. Araldite Rapid type | [🔗 Search](https://www.aliexpress.com/w/wholesale-two-part-epoxy-adhesive-rapid.html) |

> ⚠️ **AliExpress note:** Always check seller ratings and order a few extra of small parts (bolts, nuts, inserts). The M8 threaded rod search will return both smooth and threaded variants — make sure you select **threaded** (fully threaded, M8 × 1.25 pitch). For the M10 hinge pin search **smooth rod** not threaded.

### Approximate Cost (UK)

| Category | Approx. |
|---|---|
| PETG filament × 3 spools | £42 |
| NEMA 17 + A4988 + Arduino Nano | £20 |
| M8/M10 rods + flanged bearing | £8 |
| Flexible coupler + micro-switches | £6 |
| Fasteners, inserts, nuts, bolts | £7 |
| PSU, barrel jacks, wiring | £8 |
| Foam strip, epoxy | £4 |
| 3/8"–M10 tripod adaptor | £4 |
| **Total (excl. filament)** | **~£53** |
| **Total (incl. filament)** | **~£95** |

---

## Wiring

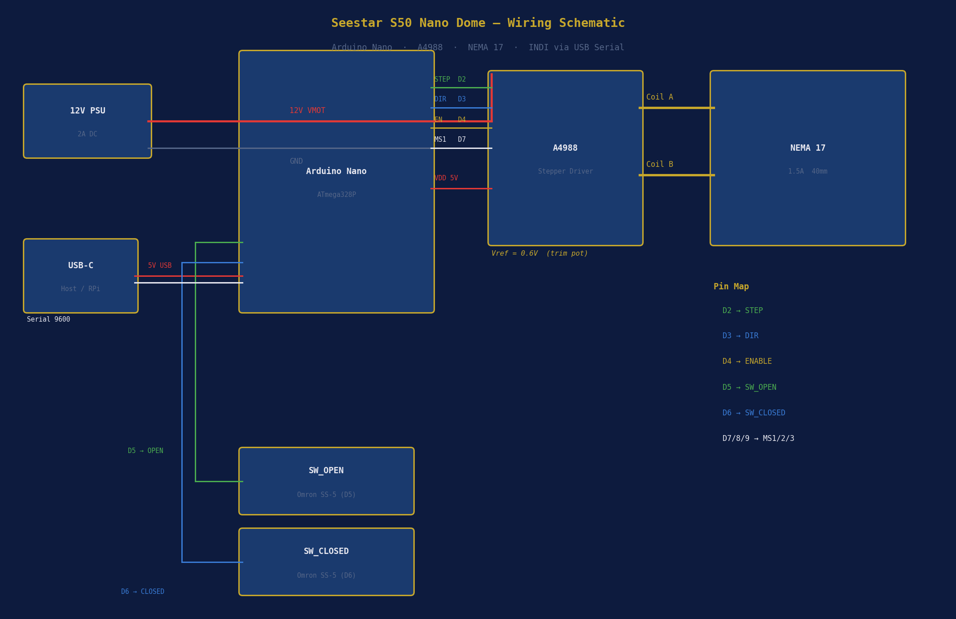
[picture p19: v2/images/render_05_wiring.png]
Wiring Schematic


### Pin Map

| Arduino Pin | Connection | Notes |
|---|---|---|
| D2 | A4988 STEP | |
| D3 | A4988 DIR | |
| D4 | A4988 ENABLE | LOW = enabled |
| D5 | SW_OPEN (NO) | Input pullup |
| D6 | SW_CLOSED (NO) | Input pullup |
| D7 | A4988 MS1 | HIGH → 1/8 microstepping |
| D8 | A4988 MS2 | LOW |
| D9 | A4988 MS3 | LOW |
| D13 | Status LED | Built-in |
| VIN | 12 V PSU | |
| 5V | A4988 VDD | |
| GND | Common ground | |

### A4988 Vref

```
Vref = Imax × 0.8 / 2 = 1.5 × 0.8 / 2 = 0.6 V
```

### Steps per mm

```
1/8 microstepping → 1600 steps/rev
M8 pitch = 1.25 mm/rev
Steps/mm = 1600 ÷ 1.25 = 1280
Full open travel (100 mm) = 128,000 steps
```

---

## Firmware

Source: [`firmware/dome_controller/dome_controller.ino`](firmware/dome_controller/dome_controller.ino)

Unchanged from V1. Full serial command reference:

| Command | Response | Description |
|---|---|---|
| `OPEN` | `OPENING` → `OPEN` | Open dome fully |
| `CLOSE` | `CLOSING` → `CLOSED` | Close dome fully |
| `STOP` | `STOPPED` | Immediate halt |
| `ABORT` | `STOPPED` | Alias for STOP |
| `STATUS` | `OPEN` / `CLOSED` + `POS:nnnnn` | Current state |
| `STEP nn` | `JOGGED:nn` | Jog ±nn steps |

```bash
arduino-cli compile --fqbn arduino:avr:nano firmware/dome_controller/dome_controller.ino
arduino-cli upload -p /dev/ttyUSB0 --fqbn arduino:avr:nano firmware/dome_controller/dome_controller.ino
```

---

## INDI Driver

Source: [`indi/seestar_nano_dome.cpp`](indi/seestar_nano_dome.cpp)

Unchanged from V1. Appears in KStars/Ekos as **"Seestar Nano Dome"** under Domes.

```bash
sudo apt install libindi-dev cmake build-essential
cd indi && mkdir build && cd build
cmake -DCMAKE_INSTALL_PREFIX=/usr ..
make -j4 && sudo make install
indiserver -v indi_seestar_nano_dome
```

---

## Assembly

### Alt/Az Assembly

Alt/Az Assembly

**Stack order (bottom to top):** Alt/Az Adapter (02a) → Base Ring (01) → Dome Lower (03) → Dome Upper (04)

1. Press M10 brass insert into adapter plate centre (heat press or epoxy)
2. Bolt adapter to base ring bottom flange — 6× M5 × 16, finger tight
3. Mount NEMA 17 in base ring rear pocket (M3 × 8 bolts)
4. Fit flexible coupler on motor shaft; thread M8 lead screw through bore
5. Install bearing block with F688 bearing; secure inside base ring
6. Snap Arduino Nano tray and A4988 into electronics bay; wire per diagram
7. Set A4988 Vref to 0.6 V
8. Seat lower dome half on base ring top flange — 6× M4 bolts
9. Interleave M10 hinge knuckles; slide M10 × 100 mm pin through; fit retainer clips
10. Thread lead screw through lower dome nut trap; attach pivot arm to lid
11. Fit limit switch brackets; wire to D5/D6
12. Press 3 mm foam strip into lid seal groove
13. Thread dome assembly onto S50 tripod via 3/8" insert — snug, not over-tightened

### EQ Assembly

EQ Assembly

**Stack order (bottom to top):** EQ Adapter (02b bottom) → EQ Collar (02b top) → Base Ring (01) → Dome Lower (03) → Dome Upper (04)

1. Bolt EQ adapter to your wedge top plate — 4× M4 × 12 into 60 mm square pattern
2. Sit EQ collar on top of adapter; 6× M5 bolts at base
3. Bolt base ring to top of EQ collar — 6× M5 bolts
4. Continue from step 3 of Alt/Az assembly (motor, firmware, dome shells, hinge)
5. **Do not** fit the M10 tripod brass insert — not needed in EQ mode

---

## Commissioning

- [ ] Motor direction correct — `OPEN` extends lead screw and lifts lid
- [ ] If lid closes on `OPEN` command: swap motor coil pair (1B or 2B on A4988)
- [ ] SW_CLOSED trips before lid crushes base ring — adjust bracket position
- [ ] SW_OPEN trips before lead screw bottoms out
- [ ] Scope rotates freely inside dome at all Alt/Az positions (Alt/Az mode)
- [ ] Scope rotates freely on RA axis at 53° polar tilt without touching dome (EQ mode)
- [ ] Crown slot clears scope barrel at all pointing positions
- [ ] INDI `STATUS` shows `OPEN` / `CLOSED` correctly in Ekos
- [ ] Foam seal compresses evenly when dome is closed
- [ ] Slot rain cover (5g) snaps on and off cleanly

---

## Integration with Seestar ALP

[Seestar ALP](https://github.com/smart-underworld/seestar_alp) provides scheduling and mosaic control. With `indiserver` and `indi_seestar_nano_dome` both running, KStars/Ekos will automatically open the dome before a session and close/park it on abort or weather alert.

```bash
# Weather-triggered close via MQTT
mosquitto_sub -t 'weather/alert' | while read msg; do
  echo "CLOSE" > /dev/ttyUSB0
done
```

---

## Repository Structure

```
SmartScopeAutomatedDome/
├── openscad/
│   ├── params.scad               # All dimensions — edit here first
│   ├── 01_base_ring.scad         # Universal base ring (both modes)
│   ├── 02a_adapter_altaz.scad    # Alt/Az adapter plate
│   ├── 02b_eq_extension.scad     # EQ extension collar + adapter
│   ├── 03_dome_lower.scad        # Dome lower half
│   ├── 04_dome_upper.scad        # Dome upper half (crown slot)
│   └── 05_hardware_parts.scad    # All small parts, one plate
├── 3mf/
│   ├── 01_base_ring.3mf
│   ├── 02a_adapter_altaz.3mf
│   ├── 02b_eq_extension.3mf
│   ├── 03_dome_lower.3mf
│   ├── 04_dome_upper.3mf
│   └── 05_hardware_parts.3mf
├── firmware/
│   └── dome_controller/
│       └── dome_controller.ino
├── indi/
│   ├── seestar_nano_dome.cpp
│   ├── CMakeLists.txt
│   └── indi_seestar_nano_dome.xml
├── images/
│   ├── render_00_mode_comparison.png
│   ├── render_00_altaz_assembly.png
│   ├── render_00_eq_assembly.png
│   ├── render_01_base_ring.png
│   ├── render_02a_adapter_altaz.png
│   ├── render_02b_eq_extension.png
│   ├── render_03_dome_lower.png
│   ├── render_04_dome_upper.png
│   ├── render_05_hardware_parts.png
│   ├── render_05_wiring.png
│   └── render_06_architecture.png
└── README.md
```

---

## Contributing

Pull requests welcome. To adapt for a different scope or latitude:

- **Different scope body:** Update `s50_w`, `s50_d`, `s50_h` in `openscad/params.scad`
- **Different latitude:** Update `LATITUDE` in `params.scad` — wedge tilt and EQ collar clearances recalculate automatically
- **Different wedge bolt pattern:** Edit the bolt coordinates in `02b_eq_extension.scad` (clearly commented)

Please open an issue before starting significant structural changes.

---

## Licence

MIT — see [LICENSE](LICENSE) — CC BY-NC-SA 4.0, non-commercial use only.

Design inspired by the [Nano Dome V2](https://www.cloudynights.com/forums/topic/1000995-miniature-3d-printed-clamshell-observatory-nano-dome/) by spbalaji (Cloudy Nights).

---

*Built by [@neilmanfredit](https://github.com/neilmanfredit)*

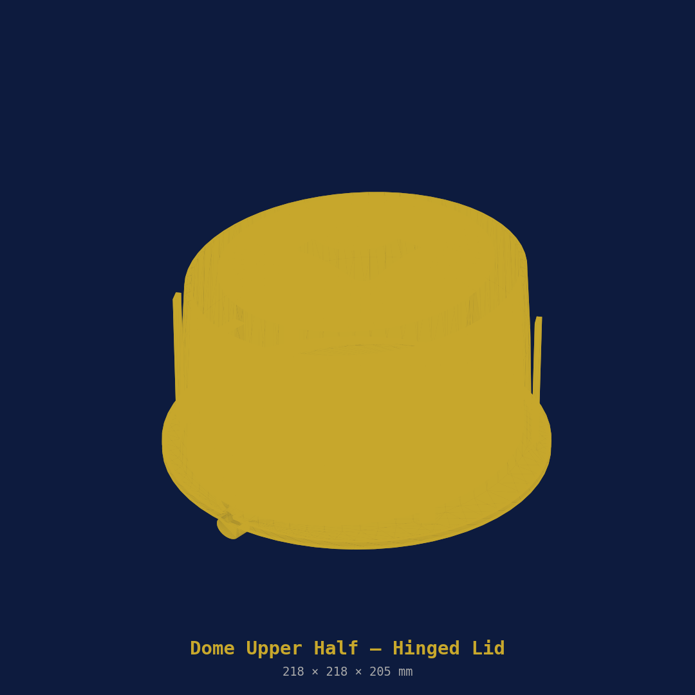
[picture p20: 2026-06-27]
images/render_03_dome_upper.png

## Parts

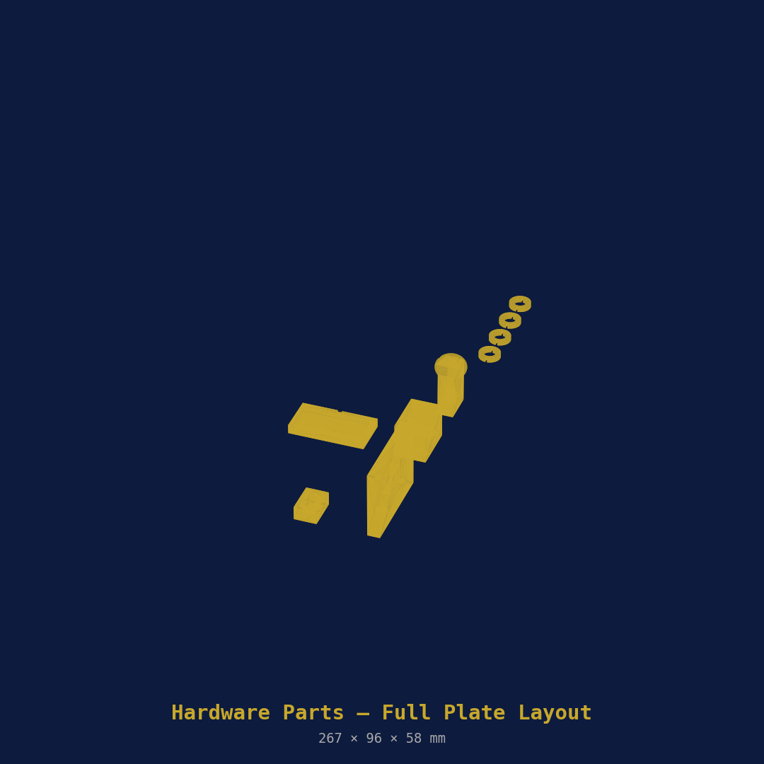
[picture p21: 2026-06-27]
images/render_04_hardware_parts.png

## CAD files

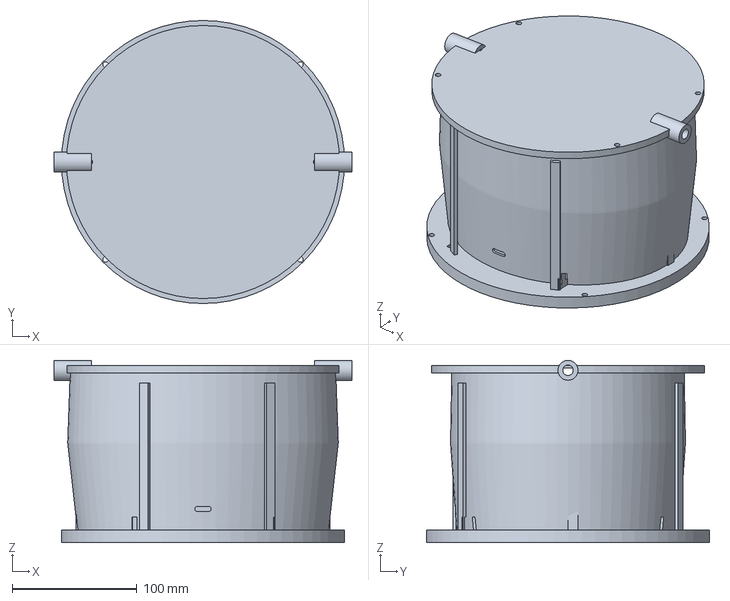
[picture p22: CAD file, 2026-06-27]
3mf/02_dome_lower.3mf
238.5 x 226.5 x 146.0 mm

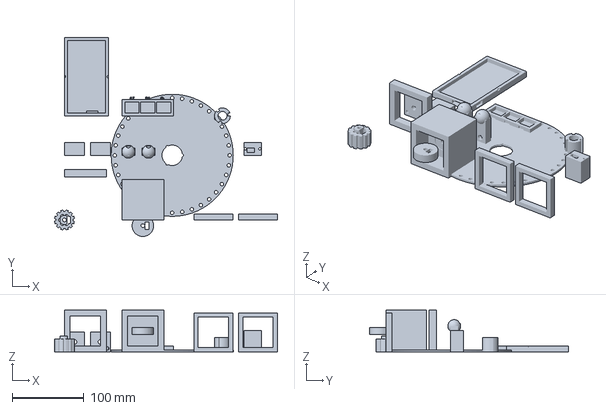
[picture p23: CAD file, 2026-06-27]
v3/3mf/04_drive_hardware.3mf
310.5 x 277.0 x 58.3 mm

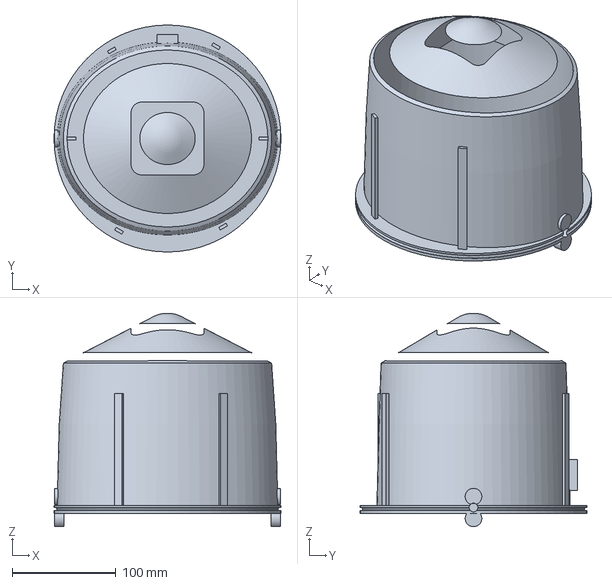
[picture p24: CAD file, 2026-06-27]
3mf/03_dome_upper.3mf
218.5 x 218.5 x 205.5 mm

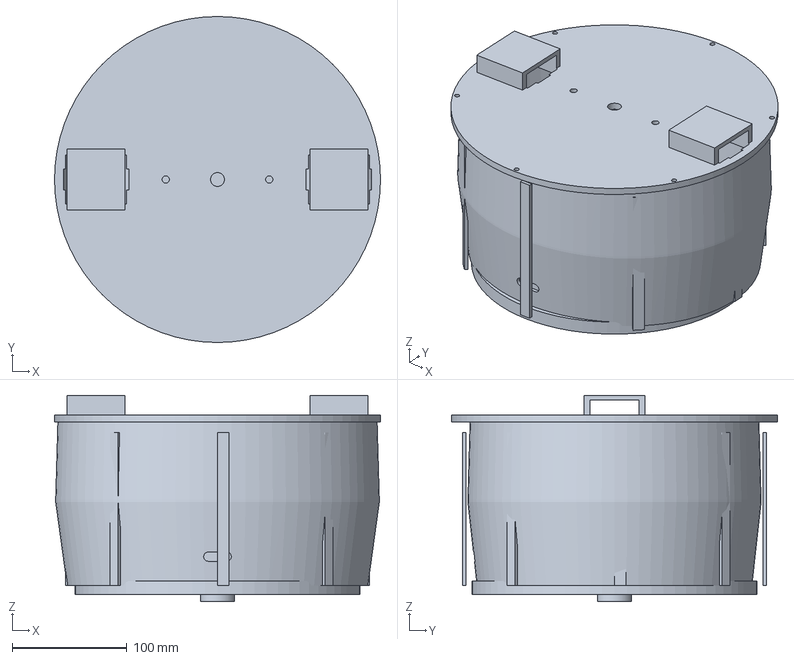
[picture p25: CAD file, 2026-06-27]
v3/3mf/02_dome_lower.3mf
283.5 x 283.5 x 179.2 mm

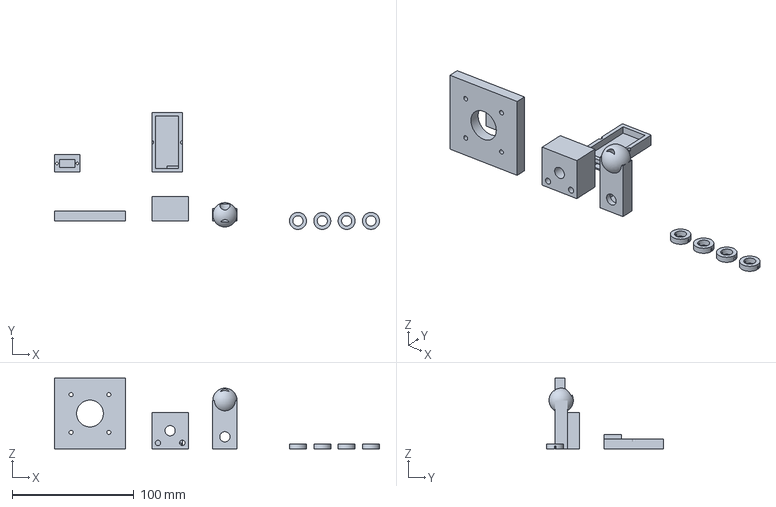
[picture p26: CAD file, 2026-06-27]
3mf/04_hardware_parts.3mf
267.0 x 96.0 x 58.3 mm

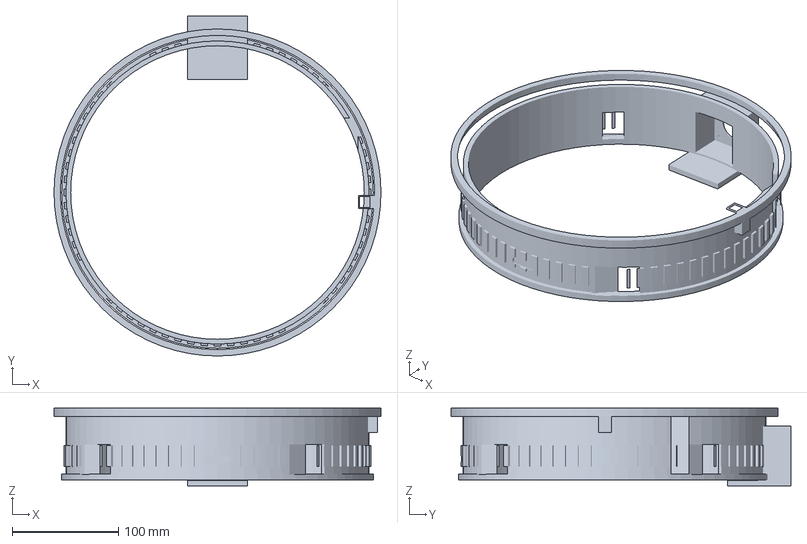
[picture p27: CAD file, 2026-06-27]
v3/3mf/01_base_ring.3mf
308.0 x 320.2 x 73.4 mm

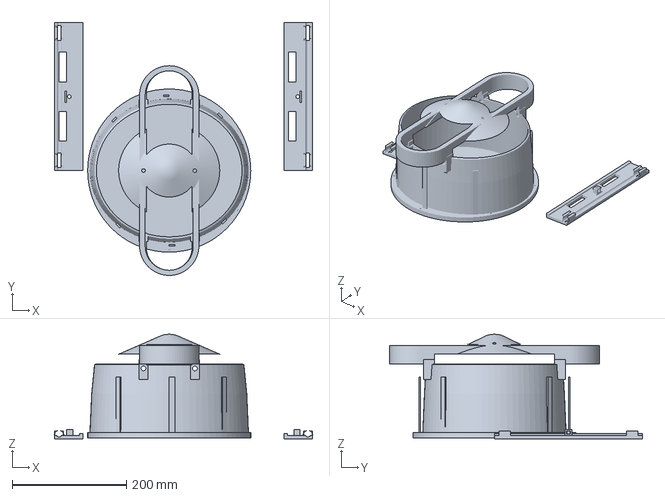
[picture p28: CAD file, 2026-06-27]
v3/3mf/03_crown_panels.3mf
451.5 x 442.5 x 183.0 mm

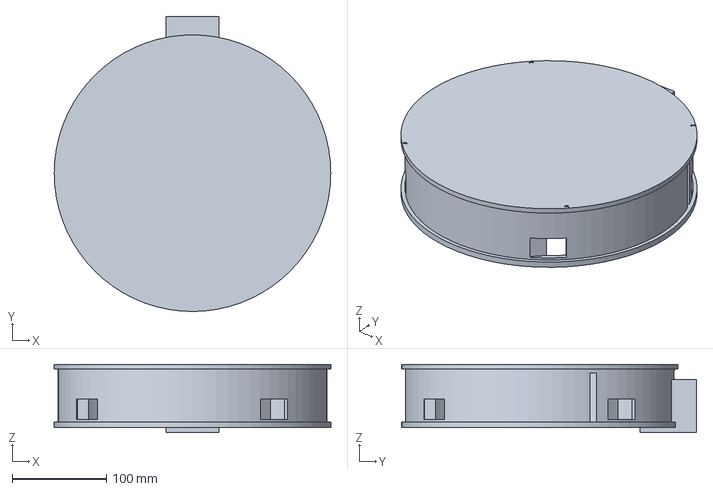
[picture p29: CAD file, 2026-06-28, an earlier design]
v2/3mf/01_base_ring.3mf
293.5 x 313.0 x 72.4 mm

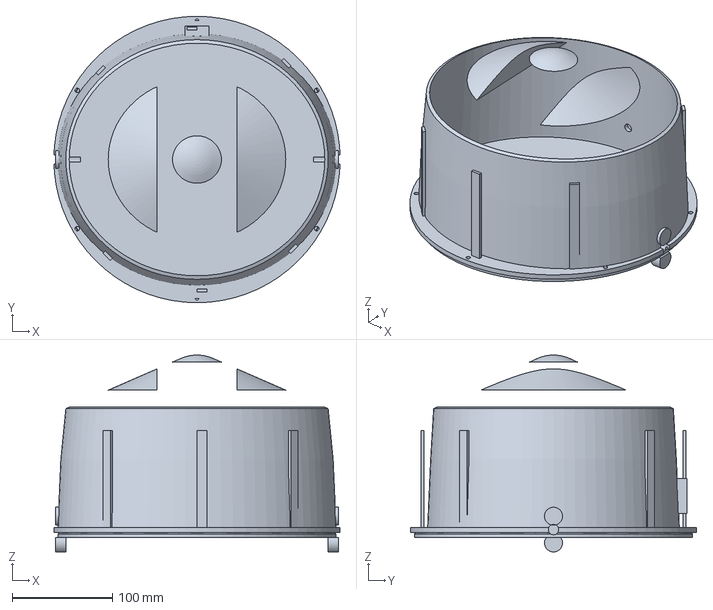
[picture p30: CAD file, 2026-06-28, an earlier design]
v2/3mf/04_dome_upper.3mf
285.1 x 285.5 x 196.3 mm

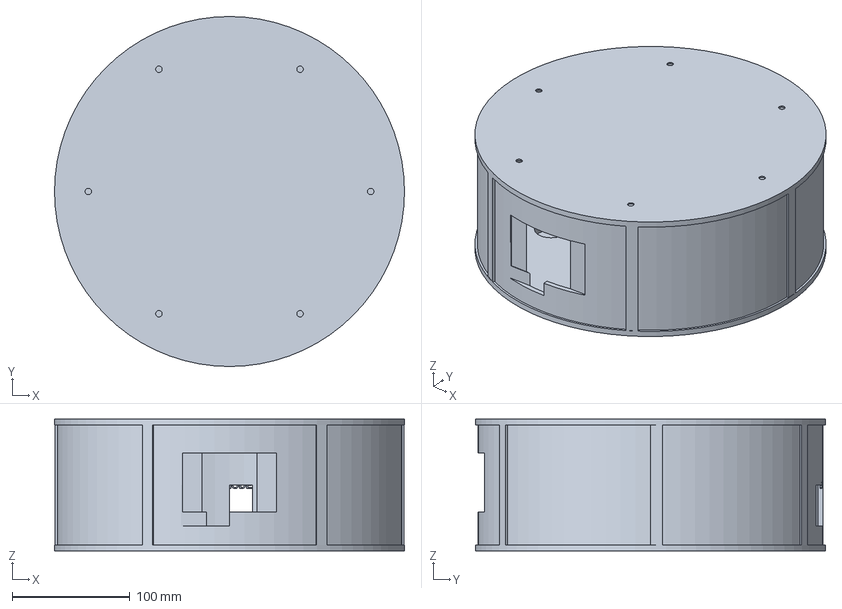
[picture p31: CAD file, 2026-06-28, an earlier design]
v2/3mf/02b_eq_extension.3mf
297.5 x 297.5 x 112.0 mm

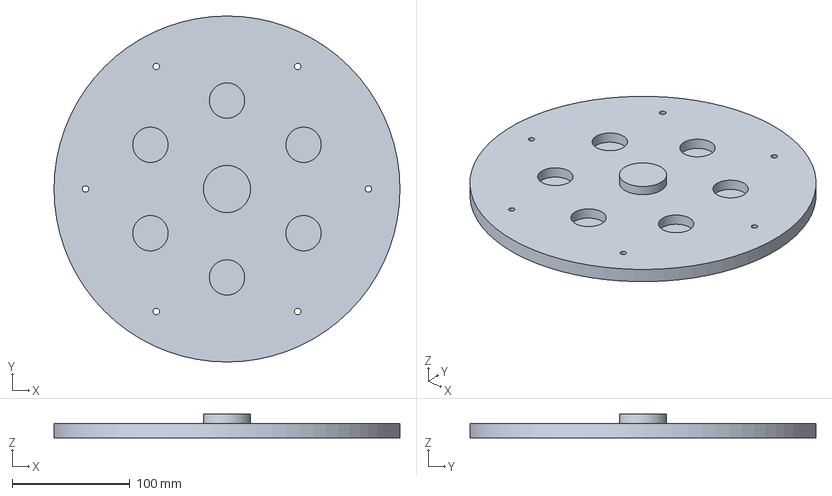
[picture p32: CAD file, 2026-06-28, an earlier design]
v2/3mf/02a_adapter_altaz.3mf
293.5 x 293.5 x 20.0 mm

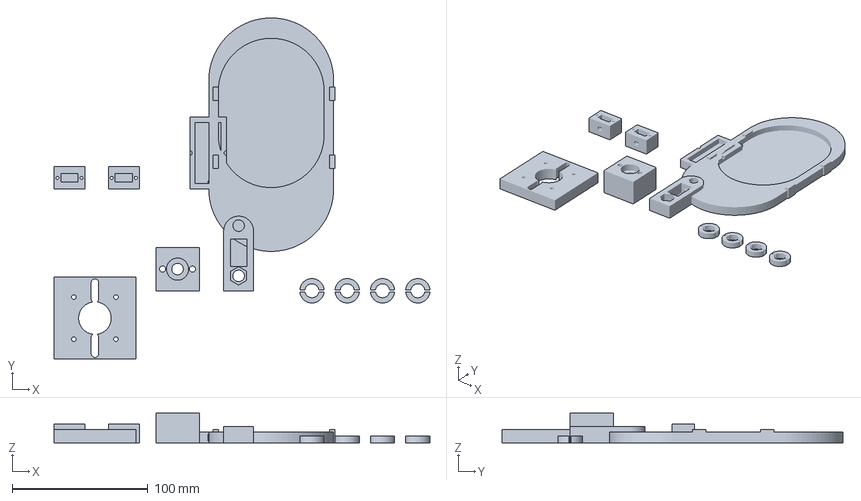
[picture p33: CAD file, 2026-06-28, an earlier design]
v2/3mf/05_hardware_parts.3mf
277.0 x 251.3 x 22.0 mm

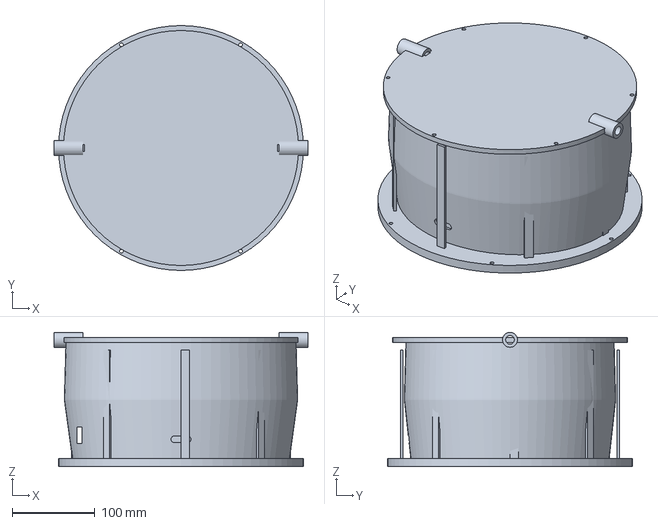
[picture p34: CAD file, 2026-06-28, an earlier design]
v2/3mf/03_dome_lower.3mf
306.5 x 295.5 x 162.0 mm

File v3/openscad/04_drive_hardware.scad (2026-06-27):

// ============================================================
// Part 04: DRIVE HARDWARE PARTS V3
// Seestar S50 Slewing Dome V3 — Bambu H2S | PETG
//
// All on one or two plates depending on bed fit.
// Export each module separately for printing.
//
// 04a — Az Pinion Gear (module 2, 12 teeth — meshes with ring gear)
// 04b — Az Friction Drive Wheel Mount (rubber wheel on dome rim)
// 04c — Az Motor Bracket (holds NEMA17 Az motor in base ring)
// 04d — Panel Motor Bracket (×2, left + right crown motors)
// 04e — M6 Panel Lead Screw Bearing Block (×2)
// 04f — Panel Lead Screw Pivot Arm (×2)
// 04g — Az Encoder Disk (36-slot, IR reflective)
// 04h — IR Sensor Bracket (mounts TCRT5000 at base ring rim)
// 04i — Arduino Mega Tray
// 04j — A4988 Triple Driver Board Tray (3× A4988 side by side)
// 04k — Slip-Ring Spacer (keeps cable tidy through centre bore)
//
// PRINT ORIENTATION: All flat, no supports
// PRINT TIME: ~4h total  |  FILAMENT: ~110g PETG
// ============================================================

include <params.scad>

// ── 04a: Az Pinion Gear ──────────────────────────────────────
// Module 2, 12 teeth. Mounts on NEMA17 shaft (5mm bore).
// Meshes with base ring ring gear (72 teeth).
// Gear ratio: 72:12 = 6:1 → 1600 steps × 6 = 9600 steps/rev
// At 1/8 microstepping: 9600 steps = 1 dome revolution
// Angular resolution: 360° / 9600 = 0.0375° per step
module az_pinion() {
    TEETH = 12;
    MODULE = 2.0;
    PD = MODULE * TEETH;  // pitch diameter = 24mm
    BORE = 5.0;           // NEMA17 shaft

    difference() {
        union() {
            // Gear body (simplified — true involute via post-process
            // or use OpenSCAD MCAD library in production)
            cylinder(d = PD + MODULE * 2, h = 18);
            // Hub
            cylinder(d = BORE + 8, h = 22);
        }
        // Shaft bore
        cylinder(d = BORE + 0.2, h = 24);
        // D-flat (NEMA17 shaft flat)
        translate([BORE / 2 - 0.5 + BORE / 4, -BORE, -1])
            cube([BORE, BORE * 2, 26]);
        // M3 set screw (radial)
        translate([PD / 2 + 2, 0, 10])
            rotate([0, 90, 0])
                cylinder(d = 3.0, h = 10);
        // Tooth profile (simplified as cylinders for printability)
        for (i = [0 : TEETH - 1])
            rotate([0, 0, i * (360 / TEETH)])
                translate([PD / 2 + MODULE * 0.8, 0, -1])
                    cylinder(d = MODULE * 1.8, h = 20);
        // Lightening
        for (i = [0:5])
            rotate([0, 0, i * 60])
                translate([PD / 4, 0, -1])
                    cylinder(d = 5, h = 20);
    }
}

// ── 04b: Friction Drive Wheel Mount ─────────────────────────
// Holds NEMA17 with a 30mm OD rubber-tired wheel
// that presses against the smooth outer rim of the rotating dome.
// Adjustable radial position via slot for preload setting.
module friction_wheel_mount() {
    translate([80, 0, 0]) {
        difference() {
            cube([NEMA17_W + 16, NEMA17_D + WALL * 2, NEMA17_W + 16]);
            // Motor pocket
            translate([NEMA17_W/2+8, -1, NEMA17_W/2+8])
                rotate([-90,0,0]) {
                    cube([NEMA17_W, NEMA17_W, NEMA17_D+4], center=true);
                    cylinder(d=22, h=NEMA17_D+6, center=true);
                    for(x=[-1,1],y=[-1,1])
                        translate([x*15.5,y*15.5,-NEMA17_D/2-3])
                            cylinder(d=3.4,h=8);
                }
            // Adjustment slots (×2, radial)
            for(z=[8, NEMA17_W+8])
                translate([NEMA17_W/2+8, NEMA17_D+WALL, z])
                    rotate([-90,0,0])
                        hull() {
                            translate([-6,0,0]) cylinder(d=5.5,h=12);
                            translate([ 6,0,0]) cylinder(d=5.5,h=12);
                        }
            // Wheel shaft bore (5mm)
            translate([NEMA17_W/2+8,-1,NEMA17_W/2+8])
                rotate([-90,0,0])
                    cylinder(d=5.3,h=NEMA17_D+8);
        }
        // Rubber wheel (30mm OD, 10mm wide — order separately)
        // Print a spacer for the wheel hub:
        translate([NEMA17_W/2+8, -8, NEMA17_W/2+8])
            difference() {
                cylinder(d=FRICT_WHEEL_D, h=10, center=true);
                cylinder(d=5.3, h=12, center=true);
                // D-flat
                translate([5/2-0.5+5/4,-5,-7])
                    cube([5,10,14]);
            }
    }
}

// ── 04c: Az Motor Bracket ────────────────────────────────────
module az_motor_bracket() {
    translate([0, 60, 0]) {
        difference() {
            cube([NEMA17_W+16, 10, NEMA17_W+16]);
            translate([NEMA17_W/2+8,-1,NEMA17_W/2+8])
                rotate([-90,0,0]) {
                    cube([NEMA17_W,NEMA17_W,NEMA17_D+4],center=true);
                    cylinder(d=22,h=NEMA17_D+6,center=true);
                    for(x=[-1,1],y=[-1,1])
                        translate([x*15.5,y*15.5,-NEMA17_D/2-3])
                            cylinder(d=3.4,h=10);
                }
            for(z=[10,NEMA17_W+6])
                translate([NEMA17_W/2+8,12,z])
                    rotate([-90,0,0])
                        hull() {
                            translate([0,-5,0]) cylinder(d=5.5,h=10);
                            translate([0, 5,0]) cylinder(d=5.5,h=10);
                        }
        }
    }
}

// ── 04d: Panel Motor Bracket (×2) ────────────────────────────
module panel_motor_bracket() {
    translate([180, 0, 0]) {
        for(i=[0,1])
            translate([i*(NEMA17_W+20), 0, 0]) {
                difference() {
                    cube([NEMA17_W+12, 8, NEMA17_W+12]);
                    translate([NEMA17_W/2+6,-1,NEMA17_W/2+6])
                        rotate([-90,0,0]) {
                            cube([NEMA17_W,NEMA17_W,NEMA17_D+4],center=true);
                            cylinder(d=22,h=NEMA17_D+6,center=true);
                            for(x=[-1,1],y=[-1,1])
                                translate([x*15.5,y*15.5,-NEMA17_D/2-3])
                                    cylinder(d=3.4,h=8);
                        }
                    for(z=[8,NEMA17_W+4])
                        translate([NEMA17_W/2+6,10,z])
                            rotate([-90,0,0])
                                cylinder(d=4.5,h=10);
                }
            }
    }
}

// ── 04e: M6 Lead Screw Bearing Block (×2) ────────────────────
module panel_bearing_block() {
    translate([0, 90, 0]) {
        for(i=[0,1])
            translate([i*36, 0, 0]) {
                difference() {
                    cube([28, 18, 28]);
                    translate([14,-1,14])
                        rotate([-90,0,0])
                            cylinder(d=PANEL_LS_D+0.4,h=22);
                    // F626ZZ pocket (6mm bore, 19mm OD, 6mm)
                    translate([14,14,14])
                        rotate([-90,0,0])
                            cylinder(d=19.2,h=7);
                    for(x=[4,24])
                        translate([x,-1,5])
                            rotate([-90,0,0])
                                cylinder(d=4.5,h=22);
                }
            }
    }
}

// ── 04f: Panel Lead Screw Pivot Arms (×2) ────────────────────
module panel_pivot_arms() {
    translate([80, 90, 0]) {
        for(i=[0,1])
            translate([i*28, 0, 0]) {
                difference() {
                    union() {
                        cube([18, 10, 36]);
                        translate([9,5,36]) sphere(d=18);
                    }
                    translate([9,-1,9])
                        rotate([-90,0,0])
                            cylinder(d=PANEL_LS_D+0.4,h=14);
                    translate([9,4,9])
                        rotate([-90,30,0])
                            cylinder(d=11.6,h=5.5,$fn=6);
                    translate([9,-1,40])
                        rotate([-90,0,0])
                            cylinder(d=PANEL_LS_D+0.4,h=14);
                }
            }
    }
}

// ── 04g: Az Encoder Disk ─────────────────────────────────────
// 36 reflective/non-reflective slots for TCRT5000 IR sensor
// Mounts on dome lower shell underside hub
module encoder_disk() {
    translate([150, 90, 0]) {
        difference() {
            cylinder(d = ENCODER_R * 2 + 10, h = 3);
            // Centre bore (fits over hub)
            cylinder(d = 28.5, h = 4);
            // 36 slots (alternating black/white = IR trigger)
            for(i=[0:ENCODER_SLOTS-1])
                rotate([0,0,i*(360/ENCODER_SLOTS)])
                    translate([ENCODER_R,0,-0.1])
                        cylinder(d=5,h=4);
            // M3 mount holes (×3)
            for(a=[0,120,240])
                rotate([0,0,a])
                    translate([14,0,-0.1])
                        cylinder(d=3.4,h=4);
        }
    }
}
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

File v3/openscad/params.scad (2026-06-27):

// ============================================================
// Seestar S50 Slewing Dome V3 — Shared Parameters
// Printer: Bambu Lab H2S  |  Material: PETG
// Three-motor: Az rotation + Panel A + Panel B
// ============================================================

// --- Seestar S50 ---
s50_w  = 142.5;
s50_d  = 130.0;
s50_h  = 257.0;

// --- Interior clearances (same generous sizing as V2) ---
CLEAR_SIDE  = 55;
CLEAR_FRONT = 50;
CLEAR_TOP   = 40;

inner_w = s50_w + CLEAR_SIDE  * 2;   // 252.5
inner_d = s50_d + CLEAR_FRONT * 2;   // 230.0
dome_h  = s50_h + CLEAR_TOP;         // 297.0

// --- Dome shell geometry ---
SPLIT_Z   = 145;    // lower/upper shell split height
WALL      = 4.5;    // shell wall thickness
RIB_T     = 3.0;
RIB_H     = 10.0;

OW    = inner_w + WALL * 2;   // ~261mm outer width
OD_s  = inner_d + WALL * 2;   // ~239mm outer depth
LID_H = dome_h - SPLIT_Z;     // ~152mm upper section

// --- Rotation system ---
// Lazy-susan bearing: 300mm OD, 240mm ID, 8mm thick (standard)
LS_BEAR_OD  = 300;
LS_BEAR_ID  = 240;
LS_BEAR_H   = 8;

// Ring gear (on base ring outer rim, for pinion drive option)
RING_GEAR_R  = 160;   // pitch radius mm
RING_GEAR_T  = 72;    // number of teeth (5° per tooth)
RING_MODULE  = 2.0;   // module (tooth size)

// Friction wheel (rubber-tired NEMA17 drive on dome rim)
FRICT_WHEEL_D = 30;   // contact wheel diameter

// Az encoder: 36-slot disk = 10° resolution
ENCODER_SLOTS = 36;
ENCODER_R     = 80;   // disk radius

// --- Panel aperture system ---
// The dome crown has two independent sliding panels (A and B)
// Each driven by M6 lead screw (1.0mm pitch) from NEMA 17
// Panel travel: 0 (closed, covers half slot) to 80mm (fully open)
PANEL_SLOT_W   = 80;   // total slot width when both panels open
PANEL_SLOT_L   = OD_s + 20;  // slot runs full dome depth
PANEL_W        = PANEL_SLOT_W / 2 + 10;  // each panel width with overlap
PANEL_TRAVEL   = 85;   // max travel per panel (mm)

// Panel lead screw (M6 × 1.0mm for fine control)
PANEL_LS_D     = 6;
PANEL_LS_PITCH = 1.0;
// Steps per mm: 1600steps/rev ÷ 1.0mm = 1600 steps/mm
// Full panel travel: 85 × 1600 = 136,000 steps

// --- Base ring ---
BASE_OD = max(inner_w, inner_d) + WALL * 2 + 24;  // ~314mm
BASE_H  = 65;

// Bearing seat ring — base ring top face has a recessed seat
// for the lazy-susan bearing outer race
BEAR_SEAT_DEPTH = 5;   // bearing sits 5mm proud of base ring top

// --- Motors ---
NEMA17_W = 42.3;
NEMA17_D = 47.0;

// --- Hinge (panels hinge at dome crown) ---
HINGE_D = 8;
HINGE_L = 35;

// --- Fasteners ---
LS_D     = 8;    // M8 (not used for panels — panels use M6)
LS_NUT_W = 13;
LS_NUT_H = 6.5;

// --- Print settings ---
// Layer: 0.20mm | Infill: 30% Gyroid | Walls: 4 | Top/bottom: 5
// Supports: Tree auto | Brim: 5mm | Nozzle: 240°C | Bed: 70°C
// Fan: 30% | Machine: BambuLab H2S (320×320mm bed)

$fn = 72;

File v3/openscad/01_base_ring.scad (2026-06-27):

// ============================================================
// Part 01: STATIC BASE RING V3
// Seestar S50 Slewing Dome V3 — Bambu H2S | PETG
//
// This ring does NOT rotate. The dome shell sits on top via
// the lazy-susan bearing. The ring gear (72 teeth, module 2)
// is on the outer rim and is driven by the Az pinion motor.
//
// Key features:
//   - Lazy-susan bearing seat on top face (recessed 5mm)
//   - Ring gear teeth on outer circumference (pinion drive option)
//   - Friction drive rail (smooth rim, rubber-wheel option)
//   - Rear motor bay: Az motor (motor 1) + panel motors (2 & 3)
//     routed via flex cable chase to dome shell above
//   - Electronics bay: Arduino Mega 2560 + 3× A4988 drivers
//   - 6× M5 adapter plate bolts (bottom, same as V2)
//   - Az encoder IR sensor bracket (rear right)
//
// PRINT ORIENTATION: Flat, open top face up
// SUPPORTS: None required
// PRINT TIME: ~7h  |  FILAMENT: ~260g PETG
// BED: 320×320mm — rotate 45° in Bambu Studio
// ============================================================

include <params.scad>

module base_ring_v3() {
    OD = BASE_OD;
    ID = OD - WALL * 2;
    H  = BASE_H;

    difference() {
        union() {
            // Main cylinder
            cylinder(d = OD, h = H);

            // Bearing seat lip (top — bearing outer race sits here)
            translate([0, 0, H - BEAR_SEAT_DEPTH])
                difference() {
                    cylinder(d = LS_BEAR_OD + 8, h = BEAR_SEAT_DEPTH + 3);
                    cylinder(d = LS_BEAR_OD - 4, h = BEAR_SEAT_DEPTH + 4);
                }

            // Bottom flange (adapter plate)
            cylinder(d = OD + 8, h = 6);

            // ---- Ring gear on outer rim (pinion drive option) ----
            // Module 2, 72 teeth, pitch radius 160mm → OD ~328mm
            // Teeth sit proud of base ring outer surface
            for (i = [0 : RING_GEAR_T - 1]) {
                rotate([0, 0, i * (360 / RING_GEAR_T)])
                    translate([OD / 2, 0, H * 0.35])
                        cube([RING_MODULE * 2, RING_MODULE * PI, H * 0.3],
                             center = true);
            }

            // Az motor boss (rear, external)
            translate([0, OD / 2 - WALL - 2, H * 0.35])
                cube([NEMA17_W + 14, NEMA17_D + WALL * 2 + 4, NEMA17_W + 14],
                     center = true);

            // Encoder sensor bracket (right side, near rim)
            translate([OD / 2 - 10, -15, H - 20])
                cube([18, 12, 22]);
        }

        // Interior bore
        translate([0, 0, -0.1])
            cylinder(d = ID, h = H + 1);

        // Bearing seat recess (top face — fits lazy-susan outer race)
        translate([0, 0, H - BEAR_SEAT_DEPTH - 0.1])
            cylinder(d = LS_BEAR_OD + 0.5, h = BEAR_SEAT_DEPTH + 1);

        // 6× M5 bottom bolt circle (adapter plate)
        for (a = [0, 60, 120, 180, 240, 300])
            rotate([0, 0, a])
                translate([120, 0, -0.1]) {
                    cylinder(d = 5.5, h = 10);
                    cylinder(d = 10, h = 5.5);  // countersink
                }

        // Az NEMA17 motor pocket (rear)
        translate([0, OD / 2 - WALL + 0.1, H * 0.35]) {
            rotate([90, 0, 0]) {
                cube([NEMA17_W, NEMA17_W, NEMA17_D + 6], center = true);
                for (x = [-1, 1], y = [-1, 1])
                    translate([x * 15.5, y * 15.5, -NEMA17_D / 2 - 4])
                        cylinder(d = 3.4, h = 10);
                cylinder(d = 24, h = NEMA17_D + 12, center = true);
            }
        }

        // Enlarged electronics bay (Arduino Mega 2560: 101×53mm)
        translate([ID / 2 - 62, -30, 6])
            cube([56, 100, 56]);

        // Slip-ring cable chase (centre, vertical) —
        // panel motor cables route through dome centre to stay tidy
        // as dome rotates
        translate([-4, -4, -0.1])
            cube([8, 8, H + 1]);

        // Az encoder sensor pocket (right side)
        translate([OD / 2 - 9, -14, H - 18])
            cube([10, 10, 20]);

        // Friction drive rail (smooth rim strip, for rubber wheel option)
        // Just a smooth arc — no feature needed, it IS the outer surface

        // Ventilation slots
        for (a = [45, 135, 225, 315])
            rotate([0, 0, a])
                translate([OD / 2 - WALL / 2, -22, H * 0.3])
                    cube([WALL + 3, 44, 28], center = true);

        // Cable exit (front, low — scope USB-C)
        translate([0, -(OD / 2 - 1), 20])
            rotate([90, 0, 0])
                hull() {
                    translate([-8, 0, 0]) cylinder(d = 8, h = WALL + 3);
                    translate([ 8, 0, 0]) cylinder(d = 8, h = WALL + 3);
                }
    }
}

// Lift to ensure Z-min = 0 on build plate (bottom flange drops to ~-5.4mm)
translate([0, 0, 6])
    base_ring_v3();

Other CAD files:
v3/openscad/02_dome_lower.scad
v2/openscad/01_base_ring.scad
v2/openscad/02a_adapter_altaz.scad
v2/openscad/02b_eq_extension.scad
v2/openscad/03_dome_lower.scad
v2/openscad/04_dome_upper.scad
v2/openscad/05_hardware_parts.scad
v2/openscad/params.scad
v3/openscad/03_crown_panels.scad

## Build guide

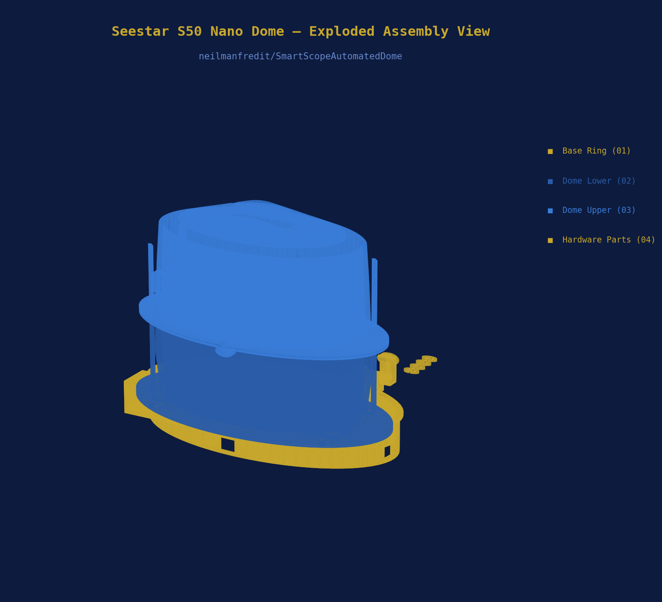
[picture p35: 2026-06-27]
images/render_00_assembly.png

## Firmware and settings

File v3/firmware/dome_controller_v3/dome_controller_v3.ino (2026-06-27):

/*
 * Seestar S50 Slewing Dome V3 — Arduino Mega Firmware
 * Target: Arduino Mega 2560
 *
 * Three A4988 stepper drivers:
 *   Motor 1 (AZ)  — dome azimuth rotation
 *   Motor 2 (PA)  — Panel A (left aperture panel)
 *   Motor 3 (PB)  — Panel B (right aperture panel)
 *
 * Az position feedback: TCRT5000 IR encoder, 36 slots
 * Az resolution: 10° per slot (optical), 0.0375° per step (motor)
 *
 * Serial protocol (9600 baud, newline terminated):
 *   GOTO ddd.d    — slew dome to azimuth ddd.d degrees (0-359.9)
 *   SYNC ddd.d    — set current position = ddd.d degrees
 *   STATUS        — reply: AZ:ddd.d PA:n PB:n MOVING:n
 *   STOP          — halt all motors
 *   ABORT         — halt all motors
 *   PA OPEN       — Panel A fully open
 *   PA CLOSE      — Panel A fully closed
 *   PA POS nn     — Panel A to nn% (0=closed, 100=fully open)
 *   PB OPEN       — Panel B fully open
 *   PB CLOSE      — Panel B fully closed
 *   PB POS nn     — Panel B to nn%
 *   PANELS OPEN   — both panels fully open
 *   PANELS CLOSE  — both panels fully closed
 *   PARK          — slew to park position (Az 0°), close panels
 *   HOME          — home encoder (index mark)
 *
 * INDI slave mode is handled entirely in the INDI driver;
 * the Arduino just executes GOTO commands received over serial.
 */

#include <Arduino.h>

// ── Pin Definitions ─────────────────────────────────────────
// Motor 1 (Az rotation)
const uint8_t AZ_STEP  = 2;
const uint8_t AZ_DIR   = 3;
const uint8_t AZ_EN    = 4;
const uint8_t AZ_MS1   = 22;
const uint8_t AZ_MS2   = 23;
const uint8_t AZ_MS3   = 24;

// Motor 2 (Panel A — left)
const uint8_t PA_STEP  = 5;
const uint8_t PA_DIR   = 6;
const uint8_t PA_EN    = 7;
const uint8_t PA_MS1   = 25;
const uint8_t PA_MS2   = 26;
const uint8_t PA_MS3   = 27;

// Motor 3 (Panel B — right)
const uint8_t PB_STEP  = 8;
const uint8_t PB_DIR   = 9;
const uint8_t PB_EN    = 10;
const uint8_t PB_MS1   = 28;
const uint8_t PB_MS2   = 29;
const uint8_t PB_MS3   = 30;

// Az encoder (TCRT5000 on A0)
const uint8_t ENC_PIN  = A0;

// Panel limit switches
const uint8_t PA_LIM_CLOSE = 31;  // Panel A fully closed
const uint8_t PA_LIM_OPEN  = 32;  // Panel A fully open
const uint8_t PB_LIM_CLOSE = 33;
const uint8_t PB_LIM_OPEN  = 34;

// Status LED
const uint8_t LED_PIN  = 13;

// ── Motion Constants ────────────────────────────────────────
// Az: 6:1 gear ratio, 1/8 step → 9600 steps/revolution
const uint32_t AZ_STEPS_REV  = 9600;
const float    AZ_DEG_PER_STEP = 360.0f / AZ_STEPS_REV;  // 0.0375°

// Panel: M6 × 1.0mm pitch, 1/8 step → 1600 steps/mm
const uint32_t PANEL_STEPS_MM   = 1600;
const uint32_t PANEL_MAX_TRAVEL = 85;   // mm
const uint32_t PANEL_MAX_STEPS  = PANEL_MAX_TRAVEL * PANEL_STEPS_MM;  // 136000

// Acceleration
const uint16_t AZ_SPEED_MIN  = 4000;  // µs between steps (slow start)
const uint16_t AZ_SPEED_MAX  = 300;   // µs at cruise
const uint16_t AZ_ACCEL      = 800;   // ramp steps

const uint16_t PAN_SPEED_MIN = 3000;
const uint16_t PAN_SPEED_MAX = 400;
const uint16_t PAN_ACCEL     = 600;

// Park position
const float AZ_PARK = 0.0f;

// ── State ───────────────────────────────────────────────────
float    azCurrent    = 0.0f;   // degrees
float    azTarget     = 0.0f;
int32_t  azSteps      = 0;      // absolute step count (can be negative)

int32_t  paPos        = 0;      // Panel A steps (0=closed)
int32_t  pbPos        = 0;      // Panel B steps
bool     paOpen       = false;
bool     pbOpen       = false;
bool     azMoving     = false;
bool     panMoving    = false;

String   cmdBuffer    = "";

// Encoder state
volatile uint16_t encCount   = 0;
uint16_t          encLast    = 0;
bool              encHomed   = false;

// ── Helpers ─────────────────────────────────────────────────
void motorEnable(uint8_t enPin, bool en) {
    digitalWrite(enPin, en ? LOW : HIGH);
}

void setMicrostep(uint8_t ms1, uint8_t ms2, uint8_t ms3) {
    // 1/8 step: MS1=H MS2=H MS3=L
    digitalWrite(ms1, HIGH);
    digitalWrite(ms2, HIGH);
    digitalWrite(ms3, LOW);
}

void doStep(uint8_t stepPin) {
    digitalWrite(stepPin, HIGH);
    delayMicroseconds(2);
    digitalWrite(stepPin, LOW);
}

// Accel curve — returns step interval µs for step i of n total
uint16_t interval(uint32_t i, uint32_t n, uint16_t vMin, uint16_t vMax, uint16_t ramp) {
    uint32_t decelStart = (n > (uint32_t)ramp * 2) ? n - ramp : ramp;
    float t;
    if (i < ramp)             t = (float)i / ramp;
    else if (i > decelStart)  t = 1.0f - (float)(i - decelStart) / ramp;
    else                      t = 1.0f;
    t = constrain(t, 0.0f, 1.0f);
    return (uint16_t)(vMin - t * (vMin - vMax));
}

// Shortest rotation direction and step count for az slew
void azCalcMove(float from, float to, int32_t &steps, bool &clockwise) {
    float diff = fmod(to - from + 360.0f, 360.0f);
    if (diff > 180.0f) { diff -= 360.0f; }
    clockwise = (diff >= 0);
    steps = (int32_t)(abs(diff) / AZ_DEG_PER_STEP + 0.5f);
}

bool serialStop() {
    if (Serial.available()) {
        char c = Serial.peek();
        if (c == 'S' || c == 'A') return true;
    }
    return false;
}

// ── Az Slew ─────────────────────────────────────────────────
void azSlew(float targetDeg) {
    int32_t steps; bool cw;
    azCalcMove(azCurrent, targetDeg, steps, cw);
    if (steps == 0) { Serial.println("AZ:AT_TARGET"); return; }

    digitalWrite(AZ_DIR, cw ? HIGH : LOW);
    motorEnable(AZ_EN, true);
    azMoving = true;
    digitalWrite(LED_PIN, HIGH);

    for (int32_t i = 0; i < steps; i++) {
        if (serialStop()) { Serial.readStringUntil('\n'); break; }
        doStep(AZ_STEP);
        azSteps += cw ? 1 : -1;
        azCurrent = fmod(azSteps * AZ_DEG_PER_STEP + 3600.0f, 360.0f);
        delayMicroseconds(interval(i, steps, AZ_SPEED_MIN, AZ_SPEED_MAX, AZ_ACCEL));
    }

    motorEnable(AZ_EN, false);
    azMoving = false;
    digitalWrite(LED_PIN, LOW);
    Serial.print("AZ_DONE:"); Serial.println(azCurrent, 1);
}

// ── Panel Move ──────────────────────────────────────────────
void panelMove(uint8_t stepPin, uint8_t dirPin, uint8_t enPin,
               uint8_t limClose, uint8_t limOpen,
               int32_t &pos, int32_t targetSteps, const char *name) {
    if (targetSteps == pos) { return; }
    bool opening = (targetSteps > pos);
    int32_t steps = abs(targetSteps - pos);

    if (opening && digitalRead(limOpen) == LOW) {
        pos = PANEL_MAX_STEPS; return;
    }
    if (!opening && digitalRead(limClose) == LOW) {
        pos = 0; return;
    }

    digitalWrite(dirPin, opening ? HIGH : LOW);
    motorEnable(enPin, true);
    panMoving = true;

    for (int32_t i = 0; i < steps; i++) {
        if (serialStop()) { Serial.readStringUntil('\n'); break; }
        if (opening  && digitalRead(limOpen)  == LOW) { pos = PANEL_MAX_STEPS; break; }
        if (!opening && digitalRead(limClose) == LOW) { pos = 0; break; }
        doStep(stepPin);
        pos += opening ? 1 : -1;
        pos = constrain(pos, 0L, (long)PANEL_MAX_STEPS);
        delayMicroseconds(interval(i, steps, PAN_SPEED_MIN, PAN_SPEED_MAX, PAN_ACCEL));
    }

    motorEnable(enPin, false);
    panMoving = false;
    Serial.print(name); Serial.print("_DONE:"); Serial.println(pos);
}

int32_t pctToSteps(int pct) {
    return constrain((long)pct * PANEL_MAX_STEPS / 100L, 0L, (long)PANEL_MAX_STEPS);
}

// ── Command Parser ───────────────────────────────────────────
void processCommand(String cmd) {
    cmd.trim(); cmd.toUpperCase();

    if (cmd.startsWith("GOTO ")) {
        float az = cmd.substring(5).toFloat();
        az = fmod(az + 360.0f, 360.0f);
        Serial.print("SLEWING:"); Serial.println(az, 1);
        azSlew(az);

    } else if (cmd.startsWith("SYNC ")) {
        azCurrent = fmod(cmd.substring(5).toFloat() + 360.0f, 360.0f);
        azSteps = (int32_t)(azCurrent / AZ_DEG_PER_STEP);
        encHomed = true;
        Serial.print("SYNCED:"); Serial.println(azCurrent, 1);

    } else if (cmd == "STATUS") {
        Serial.print("AZ:"); Serial.print(azCurrent, 1);
        Serial.print(" PA:"); Serial.print((int)(100L * paPos / PANEL_MAX_STEPS));
        Serial.print(" PB:"); Serial.print((int)(100L * pbPos / PANEL_MAX_STEPS));
        Serial.print(" MOVING:"); Serial.println((azMoving || panMoving) ? 1 : 0);

    } else if (cmd == "STOP" || cmd == "ABORT") {
        motorEnable(AZ_EN, false);
        motorEnable(PA_EN, false);
        motorEnable(PB_EN, false);
        azMoving = panMoving = false;
        Serial.println("STOPPED");

    } else if (cmd == "PA OPEN") {
        panelMove(PA_STEP, PA_DIR, PA_EN, PA_LIM_CLOSE, PA_LIM_OPEN,
                  paPos, PANEL_MAX_STEPS, "PA");
    } else if (cmd == "PA CLOSE") {
        panelMove(PA_STEP, PA_DIR, PA_EN, PA_LIM_CLOSE, PA_LIM_OPEN,
                  paPos, 0, "PA");
    } else if (cmd.startsWith("PA POS ")) {
        panelMove(PA_STEP, PA_DIR, PA_EN, PA_LIM_CLOSE, PA_LIM_OPEN,
                  paPos, pctToSteps(cmd.substring(7).toInt()), "PA");

    } else if (cmd == "PB OPEN") {
        panelMove(PB_STEP, PB_DIR, PB_EN, PB_LIM_CLOSE, PB_LIM_OPEN,
                  pbPos, PANEL_MAX_STEPS, "PB");
    } else if (cmd == "PB CLOSE") {
        panelMove(PB_STEP, PB_DIR, PB_EN, PB_LIM_CLOSE, PB_LIM_OPEN,
                  pbPos, 0, "PB");
    } else if (cmd.startsWith("PB POS ")) {
        panelMove(PB_STEP, PB_DIR, PB_EN, PB_LIM_CLOSE, PB_LIM_OPEN,
                  pbPos, pctToSteps(cmd.substring(7).toInt()), "PB");

    } else if (cmd == "PANELS OPEN") {
        panelMove(PA_STEP,PA_DIR,PA_EN,PA_LIM_CLOSE,PA_LIM_OPEN,paPos,PANEL_MAX_STEPS,"PA");
        panelMove(PB_STEP,PB_DIR,PB_EN,PB_LIM_CLOSE,PB_LIM_OPEN,pbPos,PANEL_MAX_STEPS,"PB");
        Serial.println("PANELS_OPEN");

    } else if (cmd == "PANELS CLOSE") {
        panelMove(PA_STEP,PA_DIR,PA_EN,PA_LIM_CLOSE,PA_LIM_OPEN,paPos,0,"PA");
        panelMove(PB_STEP,PB_DIR,PB_EN,PB_LIM_CLOSE,PB_LIM_OPEN,pbPos,0,"PB");
        Serial.println("PANELS_CLOSED");

    } else if (cmd == "PARK") {
        Serial.println("PARKING");
        panelMove(PA_STEP,PA_DIR,PA_EN,PA_LIM_CLOSE,PA_LIM_OPEN,paPos,0,"PA");
        panelMove(PB_STEP,PB_DIR,PB_EN,PB_LIM_CLOSE,PB_LIM_OPEN,pbPos,0,"PB");
        azSlew(AZ_PARK);
        Serial.println("PARKED");

    } else if (cmd == "HOME") {
        // Slow rotation until encoder gives rising edge at slot 0
        // Then sync position to 0°
        Serial.println("HOMING");
        motorEnable(AZ_EN, true);
        digitalWrite(AZ_DIR, HIGH);
        uint16_t lastVal = analogRead(ENC_PIN);
        for (uint32_t i = 0; i < AZ_STEPS_REV + 100; i++) {
            doStep(AZ_STEP);
            uint16_t val = analogRead(ENC_PIN);
            if (val > 600 && lastVal < 400) {
                // Rising edge = slot transition = index
                azCurrent = 0.0f; azSteps = 0; encHomed = true;
                motorEnable(AZ_EN, false);
                Serial.println("HOMED");
                return;
            }
            lastVal = val;
            delayMicroseconds(800);
        }
        motorEnable(AZ_EN, false);
        Serial.println("HOME_FAILED");

    } else {
        Serial.print("ERR:UNKNOWN:"); Serial.println(cmd);
    }
}

// ── Setup ────────────────────────────────────────────────────
void setup() {
    Serial.begin(9600);

    uint8_t stepPins[] = {AZ_STEP, PA_STEP, PB_STEP};
    uint8_t dirPins[]  = {AZ_DIR,  PA_DIR,  PB_DIR};
    uint8_t enPins[]   = {AZ_EN,   PA_EN,   PB_EN};
    uint8_t ms1[]      = {AZ_MS1,  PA_MS1,  PB_MS1};
    uint8_t ms2[]      = {AZ_MS2,  PA_MS2,  PB_MS2};
    uint8_t ms3[]      = {AZ_MS3,  PA_MS3,  PB_MS3};

    for (int i = 0; i < 3; i++) {
        pinMode(stepPins[i], OUTPUT);
        pinMode(dirPins[i],  OUTPUT);
        pinMode(enPins[i],   OUTPUT);
        motorEnable(enPins[i], false);
        setMicrostep(ms1[i], ms2[i], ms3[i]);
    }

    pinMode(PA_LIM_CLOSE, INPUT_PULLUP);
    pinMode(PA_LIM_OPEN,  INPUT_PULLUP);
    pinMode(PB_LIM_CLOSE, INPUT_PULLUP);
    pinMode(PB_LIM_OPEN,  INPUT_PULLUP);
    pinMode(LED_PIN, OUTPUT);

    // Determine initial panel states from limit switches
    if (digitalRead(PA_LIM_CLOSE) == LOW) paPos = 0;
    if (digitalRead(PA_LIM_OPEN)  == LOW) paPos = PANEL_MAX_STEPS;
    if (digitalRead(PB_LIM_CLOSE) == LOW) pbPos = 0;
    if (digitalRead(PB_LIM_OPEN)  == LOW) pbPos = PANEL_MAX_STEPS;

    Serial.println("DOME_V3_READY");
    processCommand("STATUS");
}

// ── Loop ─────────────────────────────────────────────────────
void loop() {
    while (Serial.available()) {
        char c = Serial.read();
        if (c == '\n' || c == '\r') {
            if (cmdBuffer.length() > 0) {
                processCommand(cmdBuffer);
                cmdBuffer = "";
            }
        } else {
            cmdBuffer += c;
        }
    }
}

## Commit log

2026-06-27 Initial commit — OpenSCAD, 3MF, firmware, INDI driver, renders
    [01_base_ring.3mf, 02_dome_lower.3mf, 03_dome_upper.3mf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]
2026-06-27 V2: Alt/Az + EQ mode support, larger dome shell, crown slot, swappable adapters
    [01_base_ring.3mf, 01_base_ring.scad, 02a_adapter_altaz.3mf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]
2026-06-27 Add AliExpress purchase links to BOM
2026-06-27 V3: slewing dome, independent aperture panels, INDI slave mode
    [01_base_ring.3mf, 01_base_ring.scad, 02_dome_lower.3mf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]
2026-06-27 Restructure: main README with V2/V3 version guide, v2/ and v3/ subdirectories
    [01_base_ring.3mf, 01_base_ring.scad, 02a_adapter_altaz.3mf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]
2026-06-27 Fix V2 3MF files - correct geometry and Bambu Studio compatible namespaces
    [01_base_ring.3mf, 02a_adapter_altaz.3mf, 02b_eq_extension.3mf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]
2026-06-27 Fix V3 3MF files - correct geometry and Bambu Studio compatible namespaces
    [01_base_ring.3mf, 02_dome_lower.3mf, 03_crown_panels.3mf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]
2026-06-27 Fix V2 floating geometry - all parts grounded to Z=0, pivot arm redesigned flat
    [01_base_ring.3mf, 01_base_ring.scad, 02a_adapter_altaz.3mf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]
2026-06-27 Fix V3 floating geometry - all parts grounded to Z=0, panel module rewritten flat
    [01_base_ring.3mf, 01_base_ring.scad, 02_dome_lower.3mf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]
2026-06-27 Add CC BY-NC-SA 4.0 licence — non-commercial use only
    Copyright (c) 2026 Neil Manfred
    Commercial licensing: neilmanfredit@gmail.com
    https://creativecommons.org/licenses/by-nc-sa/4.0/
2026-06-28 Fix V2 3MF: snap all parts to Z=0, enable tree supports per-object in model_settings
    [01_base_ring.3mf, 02a_adapter_altaz.3mf, 02b_eq_extension.3mf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]
2026-06-28 Fix V2 3MF support settings - correct Bambu Studio plate/object config structure
    [01_base_ring.3mf, 02a_adapter_altaz.3mf, 02b_eq_extension.3mf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]
2026-06-30 Add V3 cost breakdown with and without filament
